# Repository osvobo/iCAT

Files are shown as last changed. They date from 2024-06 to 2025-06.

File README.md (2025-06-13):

# iCAT: A Multifunctional Open-Source Platform for Advanced Light Microscopy
<br>

"i" - Intuitive: iCAT represents an innovative approach to light microscopy, incorporating advanced features like intuitive axial rotation and tracking. It introduces a novel solution for imaging and studying biological specimens with enhanced capabilities, pushing the boundaries of traditional microscopy techniques. <br>
"C" - Controlled: iCAT offers precise control over specimen rotation, temperature regulation, and lighting conditions, ensuring optimal imaging conditions and experimental reproducibility. <br>
"A" - Axial: iCAT's unique capability to rotate specimens along their axial axis sets it apart from conventional light microscopy techniques, allowing researchers to observe dynamic processes and capture detailed time-lapse sequences. <br>
"T" - Tilt: iCAT offers the unique capability of "Controlled Axial Tilt" providing researchers with a 360-degree perspective. This groundbreaking feature empowers researchers to examine specimens in three dimensions, facilitating the exploration of dynamic cellular processes, developmental biology, and beyond. 
<br><br>

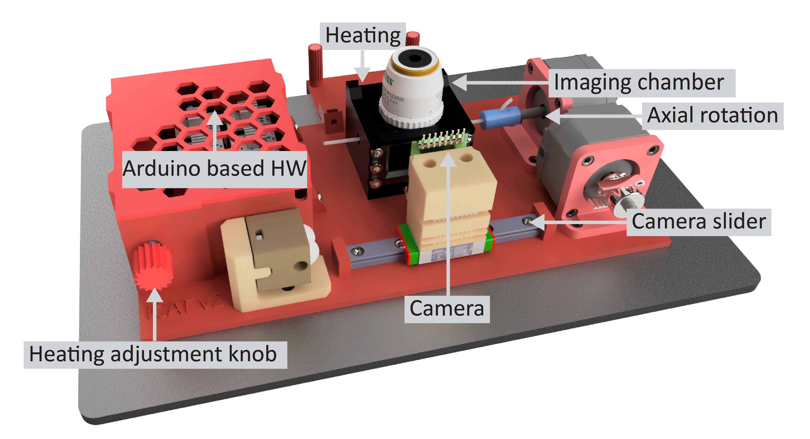
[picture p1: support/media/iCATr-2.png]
<div style="page-break-before: always;">

# Introduction
In the field of light microscopy, imaging specimens from multiple angles and maintaining controlled temperature conditions are crucial for comprehensive and accurate analysis. To address these challenges, we present iCAT, an open-source multifunctional accessory designed to revolutionize light microscopy capabilities. iCAT enables the rotation of specimens along their axial axis, incorporates an in-built thermometer and Peltier element for precise temperature control, features an integrated LED light source, and is equipped with a camera. This versatile device, controlled by an Arduino-based electronic circuit and a Processing based graphical user interface (GUI), allows researchers to capture detailed images and videos of both fixed and live specimens, such as C. Elegans, Zebrafish, Drosophila, mouse embryos etc. The iCAT accessory, which can be easily 3D-printed and assembled using readily available electrical components, serves as a powerful tool for investigating dynamic cellular processes and complex developmental phenomena. The iCAT 3D model can be visualized in this [video](https://youtu.be/drMLpkQK6RA). 
<br><br>
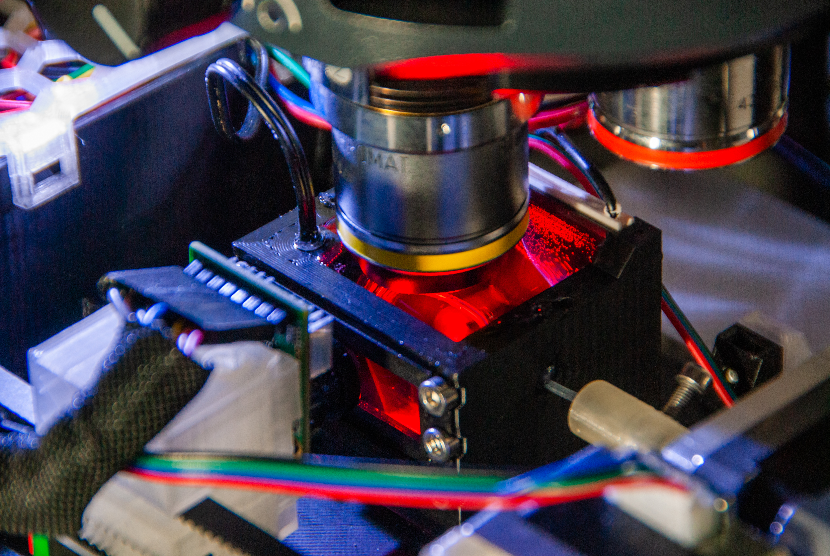
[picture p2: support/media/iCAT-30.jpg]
<div style="page-break-before: always;">

# Design and Functionality
## Rotational Capabilities
The ability to capture images and videos of a specimen from multiple angles is essential for comprehensive analysis. iCAT incorporates a motorized rotation mechanism that enables controlled and precise specimen rotation along its axial axis. Researchers can program the desired rotation parameters through the device's graphical user interface (GUI) and monitor the rotation progress in real-time. The iCAT accessory provides unprecedented flexibility in imaging and studying dynamic processes that require specimen repositioning during time-lapse experiments, such as cell migration or morphogenesis. 
<br>
## Temperature Control
Maintaining a stable and controlled temperature environment is crucial for studying living specimens. iCAT addresses this requirement through an in-built thermometer and a Peltier element. The thermometer constantly monitors the specimen's temperature, while the Peltier element actively regulates the temperature within a specified range. This temperature control feature ensures optimal imaging conditions and facilitates accurate analysis of temperature-sensitive biological processes, including embryonic development. <br>
## Illumination and Camera System
An appropriate and adjustable uniform light source is critical for obtaining images using the internal camera. The intensity of the LED can be adjusted via the GUI and minimizes the need for further external light sources during specimen rotation using the built-in camera. The GUI can control the image resolution, providing researchers with flexibility in controlling camera speed. 
<br><div style="page-break-before: always;">

# Fabrication and Accessibility
One of the key advantages of iCAT is its open-source nature, which promotes accessibility, customization, and collaborative development. The device can be fabricated using 3D printing technology, ensuring low-cost production and ease of assembly. Additionally, all the electrical components required for iCAT can be readily obtained for less than $300, making it feasible for researchers with varying resources and expertise levels to replicate and utilize the device in their laboratories. The control circuit, based on the Arduino platform, is well-documented and can be modified to accommodate specific experimental requirements. 
<br><br>
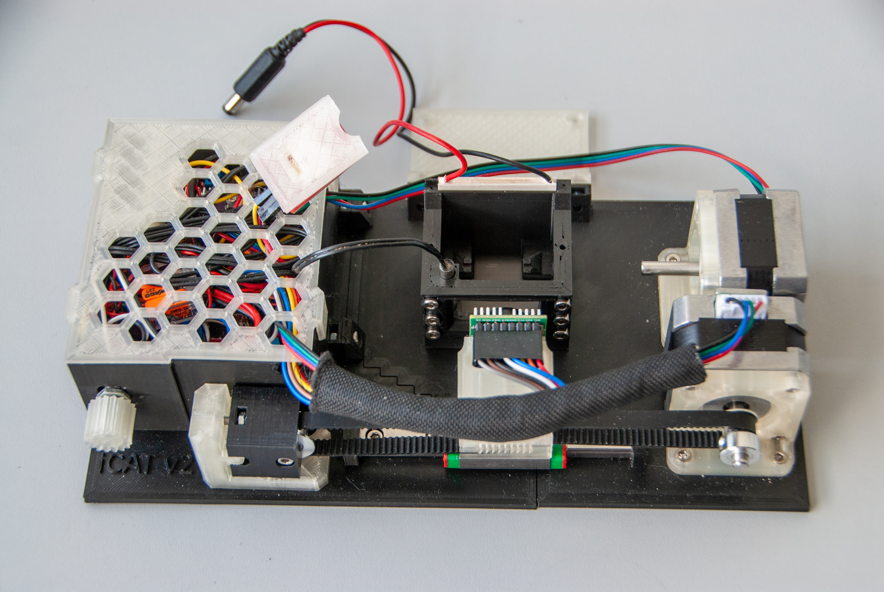
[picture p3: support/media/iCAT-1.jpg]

<br>

# Applications and Impact
The multifunctional capabilities of iCAT open up new avenues for biological research, particularly in the fields of developmental biology, neurobiology, and cellular imaging. By enabling precise specimen rotation, temperature control, illumination, and imaging, iCAT empowers researchers to investigate dynamic processes, observe intricate morphological changes, and capture real-time developmental events. The device has proven particularly effective in the study of model organisms such as C. elegans, Zebrafish, where cell migration, organogenesis, and tissue development necessitate the ability to reposition specimens during time-lapse experiments. <br>
Furthermore, the open-source nature of iCAT fosters collaboration and encourages the scientific community to contribute to its development and enhancement. By sharing the design, software, and documentation, we aim to accelerate scientific progress and provide a versatile tool that can be adapted and customized for specific research needs. <br><br>

# Conclusion
iCAT represents a significant advancement in light microscopy, addressing the limitations of traditional techniques by offering a multifunctional accessory that combines rotation, temperature control, illumination, and imaging capabilities. The open-source nature of iCAT ensures its accessibility, affordability, and adaptability, making it an invaluable tool for researchers in the biological sciences. By providing a platform to investigate dynamic processes and complex developmental phenomena, iCAT contributes to our understanding of fundamental biological mechanisms and facilitates discoveries in various fields of study.
<br><div style="page-break-before: always;">

# Methods
## Supplies
One of the key advantages of iCAT is its open-source nature, which promotes accessibility, customization, and collaborative development. The device can be fabricated using 3D printing technology, ensuring low-cost production and easy assembly. All the electrical and mechanical components required for iCAT can be readily obtained for less than $300, making it feasible for researchers with varying resources and expertise levels to replicate and utilize the device in their laboratories. For an overview of the required components, see the illustrative image and list below.
<br><br>
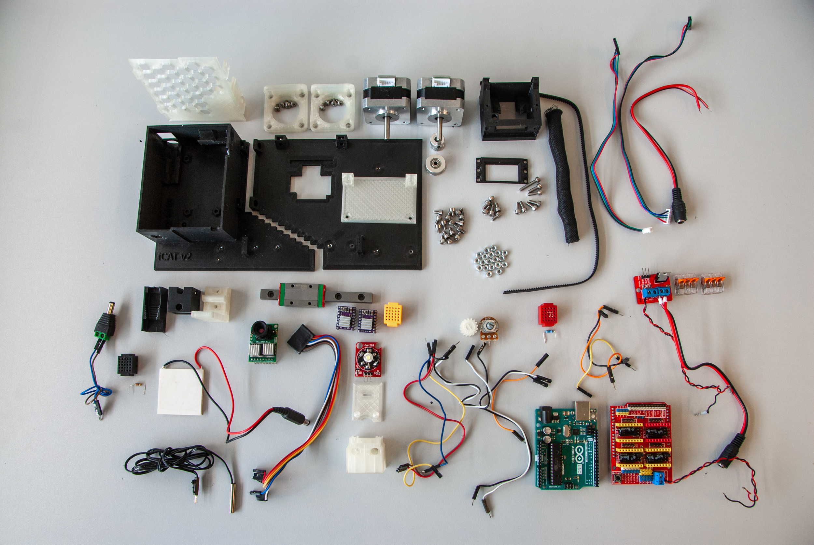
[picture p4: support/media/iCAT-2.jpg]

<br>

### Electronics:
Arduino Uno Rev3, 1x <br>
Arducam 5MP Plus OV5642, 1x <br>
IRF520 Driver Module, 1x <br>
CNC Shield V3, 1x <br>
DRV8825 Stepper Motor Driver, 2x <br>
17HS2408 Stepper Motor, 2x <br>
Peltier plate module TEC1-12706, 1x <br>
NTC Thermistor 10K 1% 3950, 1x <br>
4.7 kOhm resistor, 1x <br>
10 kOhm resistor, 1x <br>
10 kOhm potentiometer, 1x <br>
3W High Power LED Module LED with PCB Chassis for Arduino, 1x <br>
12V 3A Power Supply, 1x <br>

### Accessories:
GT2 Pulley 16 Teeth 5mm bore 6 mm width, 1x <br>
GT2 Idler 20 Teeth 5mm bore 3 mm width without teeth, 1x <br>
GT2 Open Timing Belt 2mm Pitch 6mm Width, 1x <br>
MGN9H 100mm linear guide rail with carriage, 1x <br>
Stainless Steel DIN912 Hexagon Hex Socket Head Cap Allen Bolt Screw, M3x4 (22x), M3x5 (4x), M3x6 (8x), M3x14 (1x) <br>
M3 hex nut, 20x <br>
Microscope Cover Glass, 24x40mm, 10x <br>
Lubricant in the syringe, 1x <br>
Sleeving Cord Protector, 6-12 mm, 1x <br>
Neodymium Magnet 5mm x 2mm, 8x <br>
FEP tube clear 0.8 I.D./1.2 O.D., 10-25 m <br>
FEP tube clear - other sizes, 5 m <br>
Silicon rubber tube 1x2 mm, 3 m <br>

### Wiring:
Female Plug 12V DC Power Pigtail Cable Jack, 2x <br>
Female and Male DC Connectors 2.1x5.5mm, 1x <br>
Crimp Terminals Set Kit, 1x <br>
Dupont Line M-M + F-M + F-F Jumper Wire 10cm, 20CM, 30x <br>
WAGO Terminals Series Splicing Connector 221-413, 2x <br>
Mini Solderless Prototype Breadboard, 3x <br>
Black Jumper Caps, 2x <br>

### 3D print:
3D printer, 1x <br>
3D Printer Filament 1.75mm - transparent, black, 2x <br>

### Tools:
Pipette Pump 10ml, 1x <br>
Borosilicate Glass Pasteur Pipettes, 1x <br>
Crimping Tools SN-58B + 4 jaws, 1x <br>
Screwdriver Set, 1x <br>

*NOTE: The complete shopping list is in the [components sheet](support/support.xlsx).* <div style="page-break-before: always;">

## Instructions
### Part 1: 3D printing
All 3D-printed parts can be made using PETG or PLA filaments. For the 'chamber', it is recommended to use a transparent material for the first three layers to allow the use of transmitted light from a microscope. The 'chamber' can be printed in approximately 4 hours, requiring 10.5 meters of filament. For the remaining parts, black filament is recommended to minimize light reflections. Printing these parts takes about 25 hours and consumes 75 meters of filament. The individual STL and 3MF files and the complete Fusion360 project are in the [3D folder](support/3D). The complete iCAT model can also be loaded from the [mesh folder](support/mesh). The STL data can be visualized using 3D slicer software, while the OBJ file can be opened with any mesh viewer, such as the 3D Viewer application in Windows. <br>

### Part 2: iCAT assembly
To assemble iCAT from individual parts, follow the instructions below. If needed, see the [pinout sheet](support/support.xlsx), and the wiring diagram. 
<br><br>
<!-- ![pic](support/fritzing/iCAT_v2.png) -->
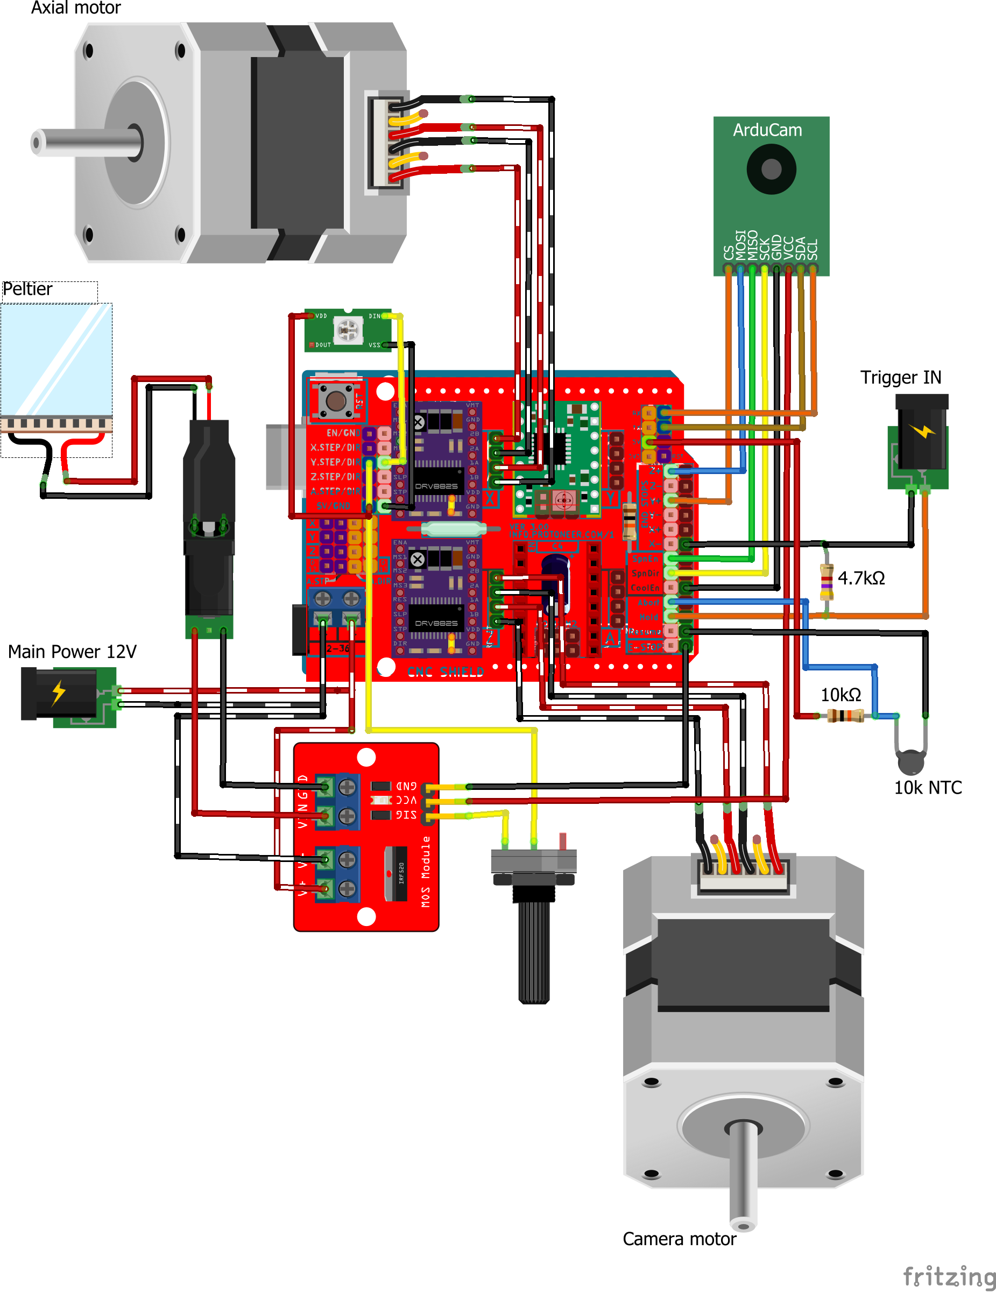
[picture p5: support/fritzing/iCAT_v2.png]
<span></span>

1. Insert all M3 nuts and four neodymium magnets into both 'base' parts. 
<br><br>
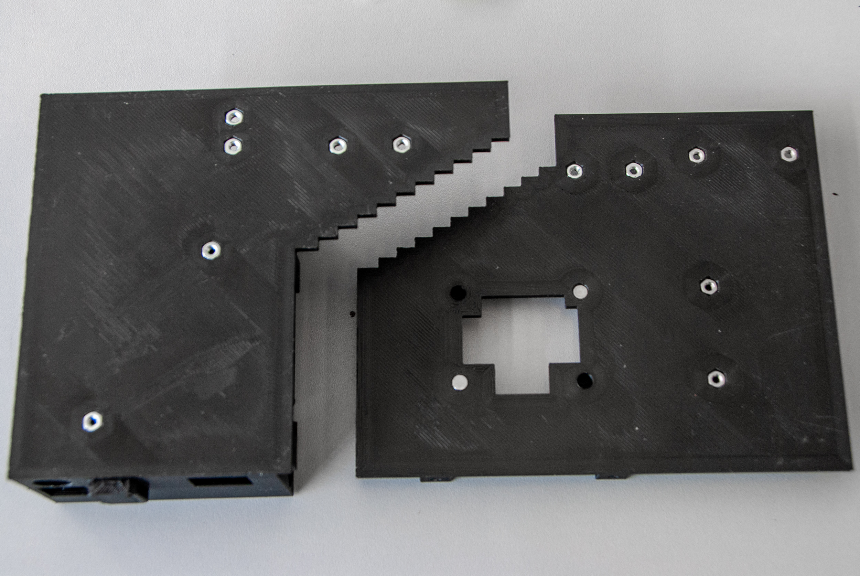
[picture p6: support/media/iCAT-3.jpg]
<span></span>

2. Slide the linear guide into the 'base-1', put both 'base' parts together, and secure the connection between them with two M3x6 screws. Attach the 'mounting plate' using two M3x6 screws and secure the 'linear guide' with four M3x5 screws.
<br><br>
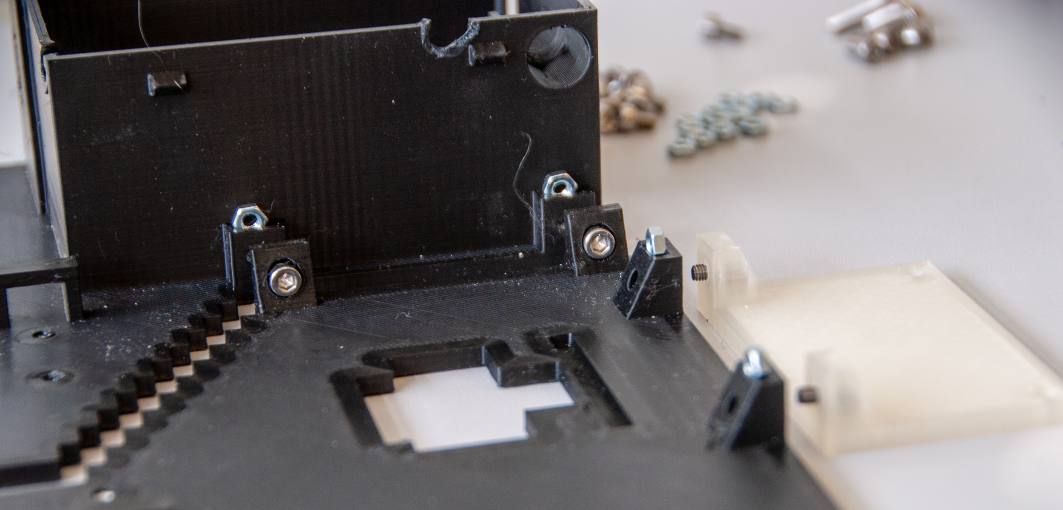
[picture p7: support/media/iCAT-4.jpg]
<span></span><div style="page-break-before: always;">
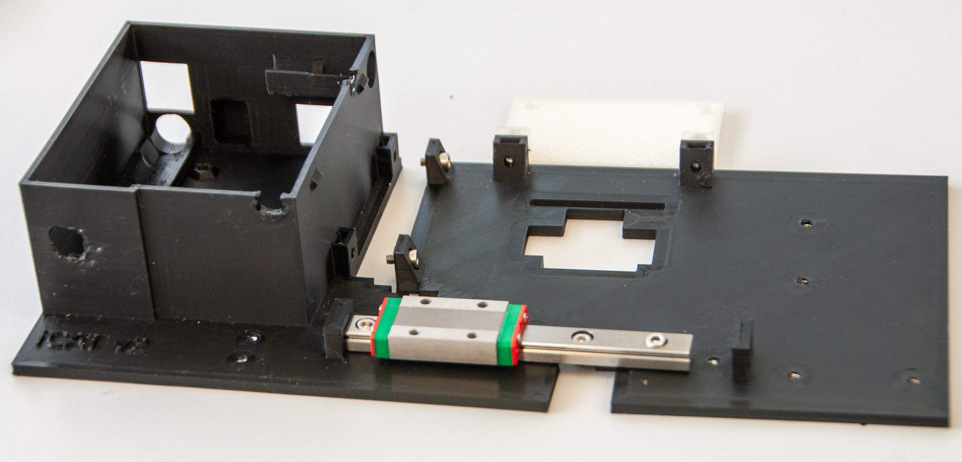
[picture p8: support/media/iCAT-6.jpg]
<span></span>

3. Fix the 'motor plates' to 'NEMA motors' using eighth M3x4 screws according to the image below. Attach 'GT2 Pulley' to one of the 'NEMA motor'. The pin connections of this 'NEMA motor' need to be oriented vertically. 
<br><br>
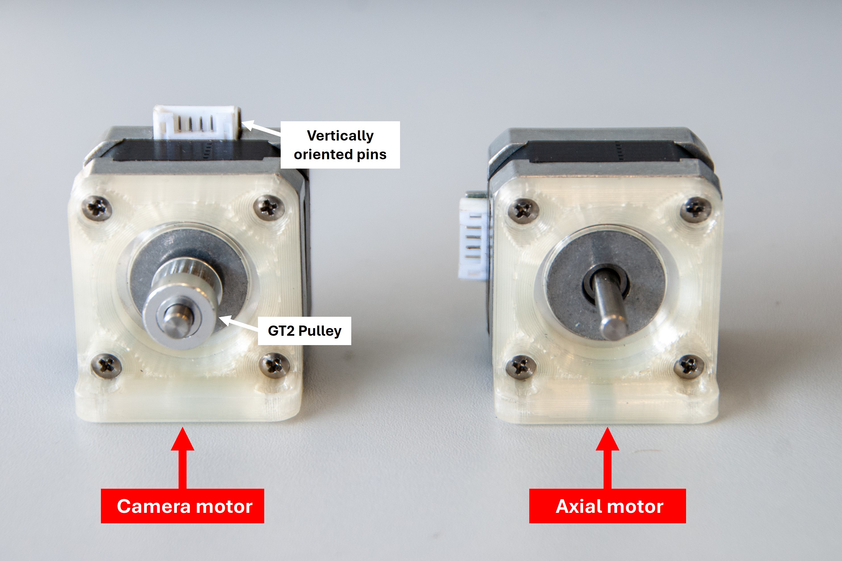
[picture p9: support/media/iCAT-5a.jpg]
<span></span>
<div style="page-break-before: always;">

4. Secure the 'motor plates' on the 'base' using M3x4 screws. 
<br><br>
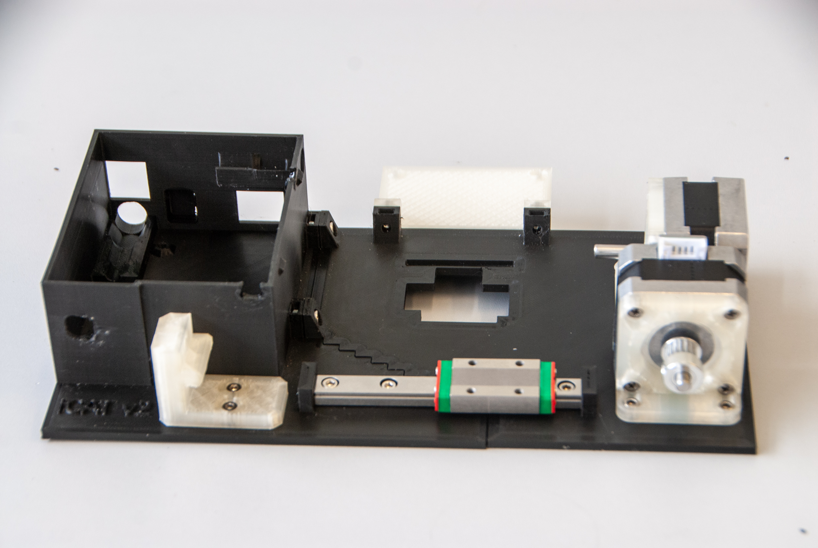
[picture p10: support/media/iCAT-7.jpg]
<span></span>

5. Insert three M3 nuts into the 'cargo plate-2' and attach the 'GT2 Idler' to it using a M3x14 screw. Cut 33.5 cm of 'GT2 Timing Belt' and pass it through the 'idler'. Fasten the ends of the belt inside the 'cargo' according to the image below. 
<br><br>
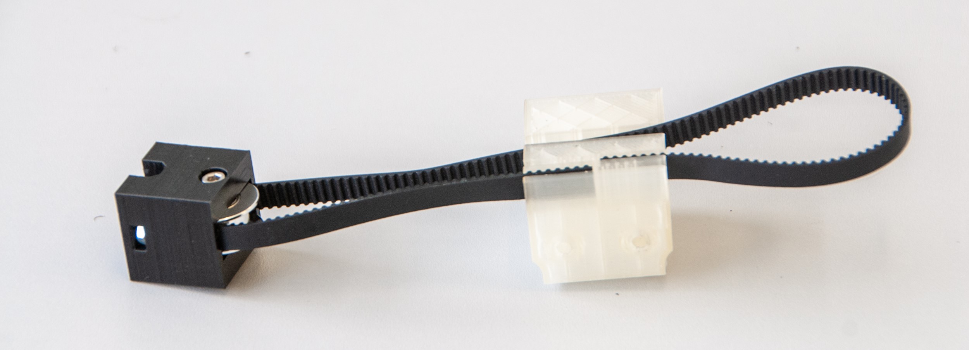
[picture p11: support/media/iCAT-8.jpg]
<span></span>
<div style="page-break-before: always;">

6. Secure the 'cargo' to the 'Linear Guide Carriage' using two M3x4 screws and place the belt on the 'GT2 Pulley' that was previously attached to one of the 'NEMA motors'. Attach the 'cargo plate-2' to the 'cargo plate-1' using prepared screws. Do not overtighten these screws, otherwise the 'base' will bend. 
<br><br>
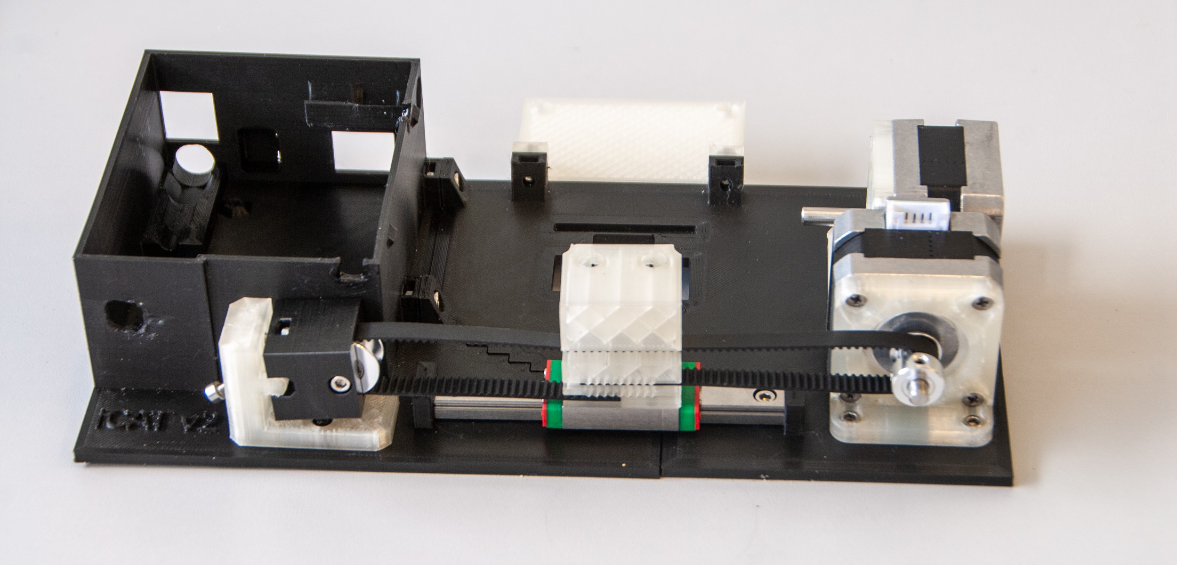
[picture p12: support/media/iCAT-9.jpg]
<span></span>

7. Insert the M3x6 screws into the mounting holes of the 'Arduino Uno' and plug the 'CNC shield' onto the 'Arduino', ensuring that the pins are properly aligned with the corresponding headers. To adjust micro-stepping (1/16 step), set up the 'M2 pin' of the 'CNC Shield' HIGH by connecting the 'black jumper caps', as shown in the image below. Attach the 'DRV8825 Stepper Motor Drivers' to the 'CNC Shield' and connect the power supply wires to both the shield and the 'WAGO terminals'. 
<br><br>
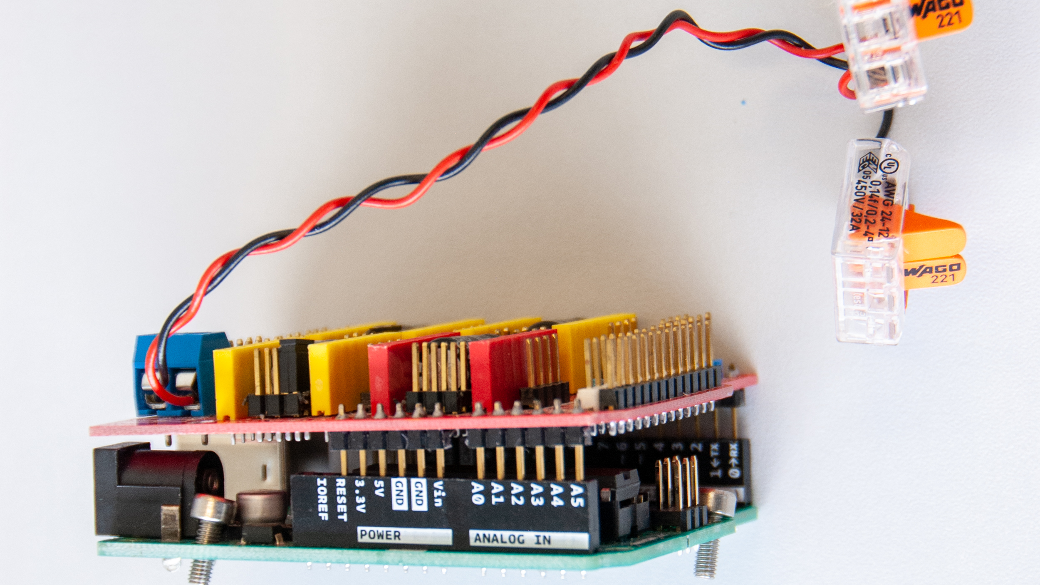
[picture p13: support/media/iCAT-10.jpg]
<span></span>

<i>NOTE: Before proceeding any further, the voltage reference (V<sub>REF</sub>) that corresponds to the maximum current that will flow to the stepper motors needs to be set. The maximum current of used stepper motors is 1.8 A. To calculate the Vref, use this equation: <br>
**V<sub>REF</sub> = I<sub>max</sub>/2** <br>
**V<sub>REF</sub> = 1.8/2 = 0.9 V** <br>
In order to set up the Vref, plug in the 'Arduino UNO' with 'CNC Shield' and the 'DRV8825 Stepper Motor Drivers' to the USB port, connect the negative probe of the multimeter to the GND, connect the positive probe of the multimeter to the screwdriver tip, set the multimeter to DC Voltage measurement, and use the screwdriver to turn the potentiometer until you get the calculated voltage.</i>
<br>

8. Similarly to the previous step, interconnect the 'WAGO terminals' with the 'IRF520 Driver Module' using additional power wires. Next, connect the wire end of the first 'Pigtail Cable Jack' to the 'WAGO terminals'. The wire end of the other 'Pigtail Cable Jack' needs to be connected to the 'IRF520 Driver Module'. If needed, crimp the ends of any wires. 
<br><br>
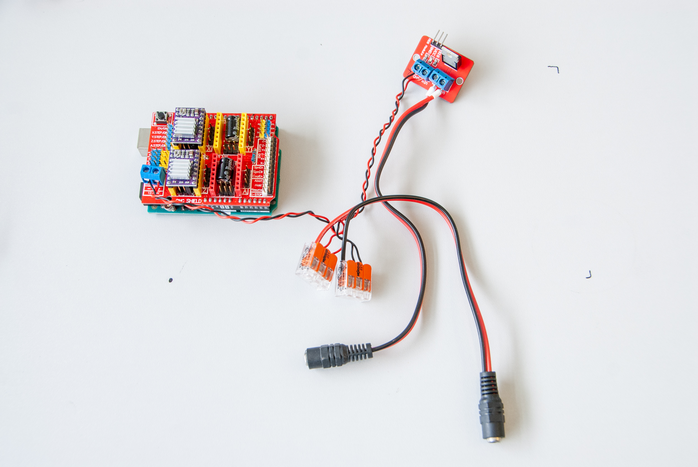
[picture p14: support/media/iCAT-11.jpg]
<span></span>

9. Attach the 'Ardunio UNO' coupled with the 'CNC Shield' and all the wirings to the 'base' using previously inserted screws. 
<br><br>
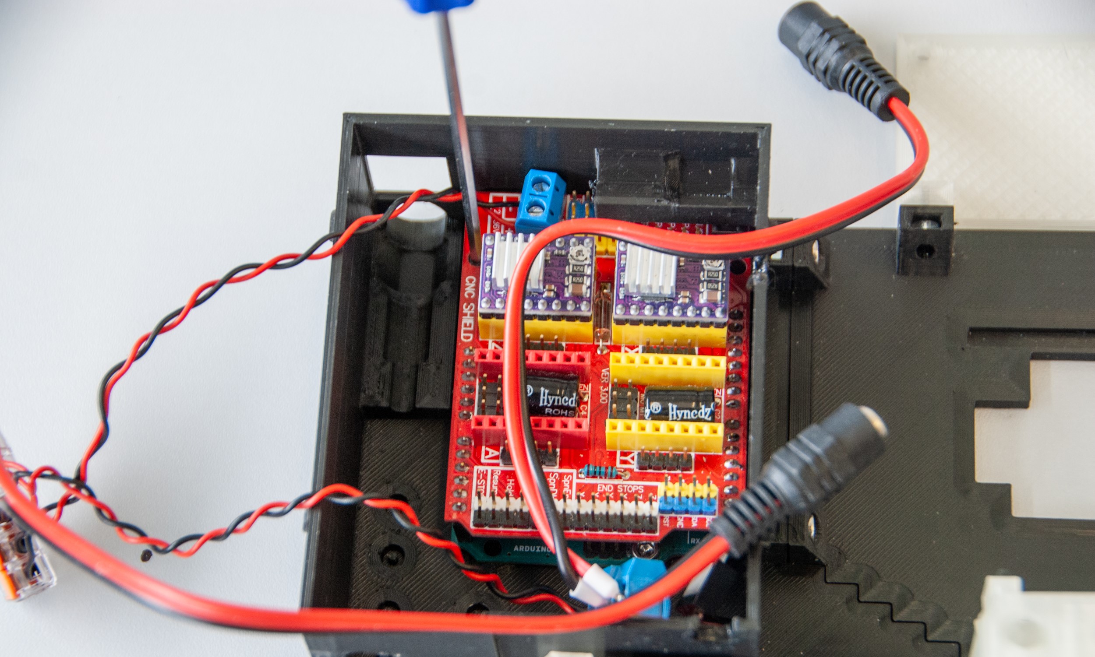
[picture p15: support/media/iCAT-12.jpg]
<span></span><div style="page-break-before: always;">

10. Install wiring components on three mini breadboards according to the image below. First, plug '10 kOhm resistor' into the 'Thermistor breadboard'. Shorten the resistor leads, if necessary. Plug '10 kOhm thermistor', while one of its leads connects it with the resistor. Connect the 'Male-Female Dupont wire' to it. This will be connected to the analog input ('Abort pin') on the 'CNC shield' later on. The other 'Dupont wires' need to be connected to the other thermistor lead (ground) and to the second resistor lead (5 V). Second, prepare the 'Trigger IN' breadboard by plugging a '4.7 kOhm resistor' into it and connecting its terminals to the 'Male DC connector'. 'Dupont wires' will be connected to both of these resistor leads later on (step 14) to the ground and to the analog input ('Hold' pin) on the 'CNC Shield'. Third, plug '10 kOhm potentiometer' into the last breadboard. Two 'Dupont wires' will be connected to the side and the middle terminals later on, connecting it to 'PWM digital input' ('Step Y' pin of the 'CNC shield') and to the 'IRF520 Driver Module' signal input. If needed, crimp the ends of any wires. 
<br><br>
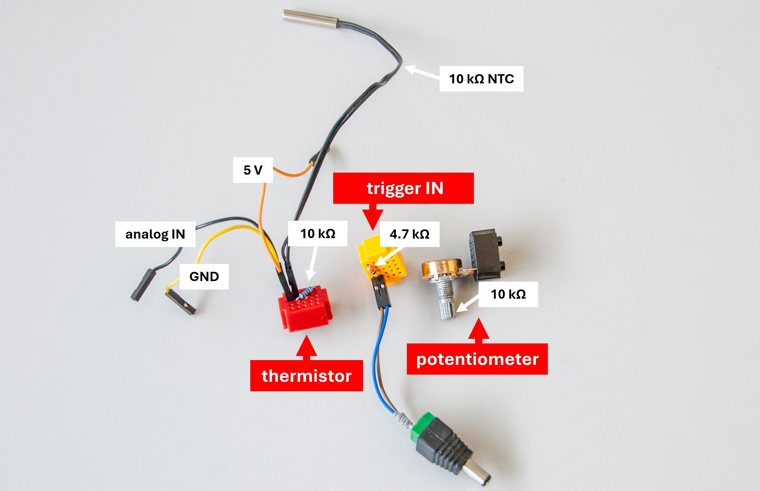
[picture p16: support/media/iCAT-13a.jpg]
<span></span><div style="page-break-before: always;">

11. Install the 'Potentiometer breadboard' and 'DC Female pigtail' in to the 'base' and cover it with the 'base adapter'. 
<br><br>
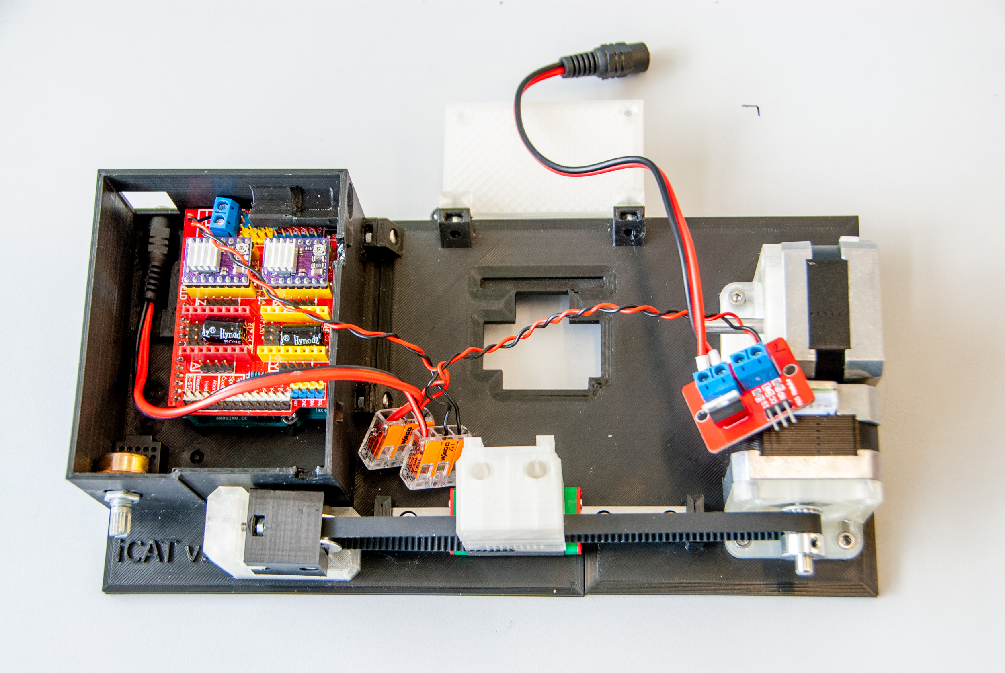
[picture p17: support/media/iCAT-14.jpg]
<span></span>

12. Install the 'Trigger IN breadboard' and fit 'Male DC connector' in the 'base adapter'. 
<br><br>
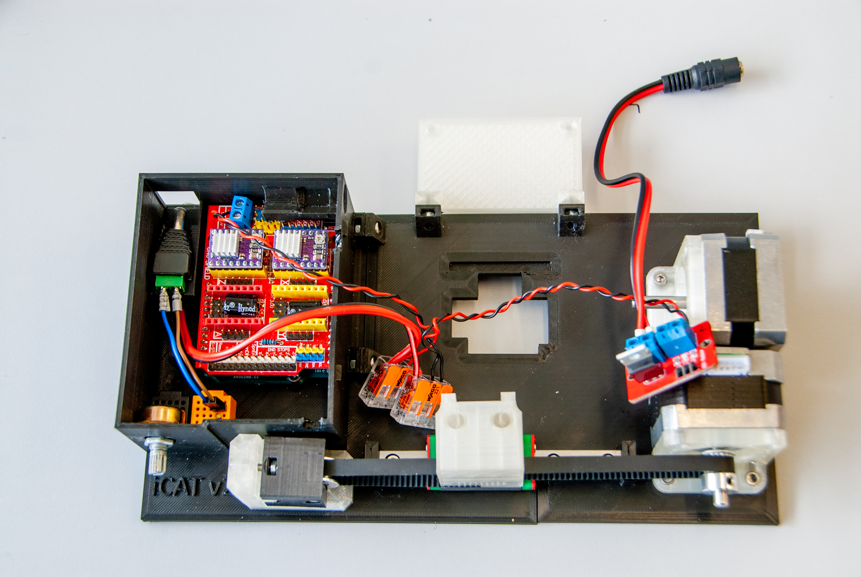
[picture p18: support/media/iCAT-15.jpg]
<span></span><div style="page-break-before: always;">

13. Install the 'IRF520 Driver Module' and plug its 'Dupont wires' (ground, 5 V). Plug the signal input as described in step 10. Fit 'Male DC connector' connected to 'IRF520 Module' in the upper right corner of the 'base'. Secure the 'potentiometer' by its nut and attach the 'knob' to it. 
<br><br>
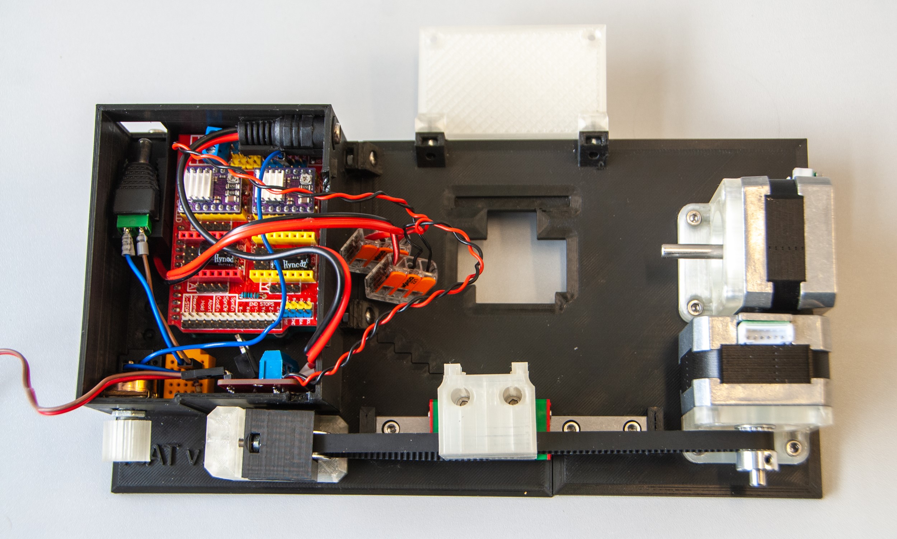
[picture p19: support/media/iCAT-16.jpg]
<span></span>

14. Install the 'Thermistor' breadboard in the 'base'. Connect 'Dupont wires' of all the 'breadboards' as described in step 10. Connect 'LED' to 5 V, ground, and digital output ('Dir Y' pin) on the 'CNC Shield'. Plug eight 'Dupont wires' to the 'Arducam' and connect them to the 'CNC Shield' according to the [pinout sheet](support/support.xlsx) and the wiring diagram. Test the functionality of the device at this point before attaching the 'lid'. 
<br><br>
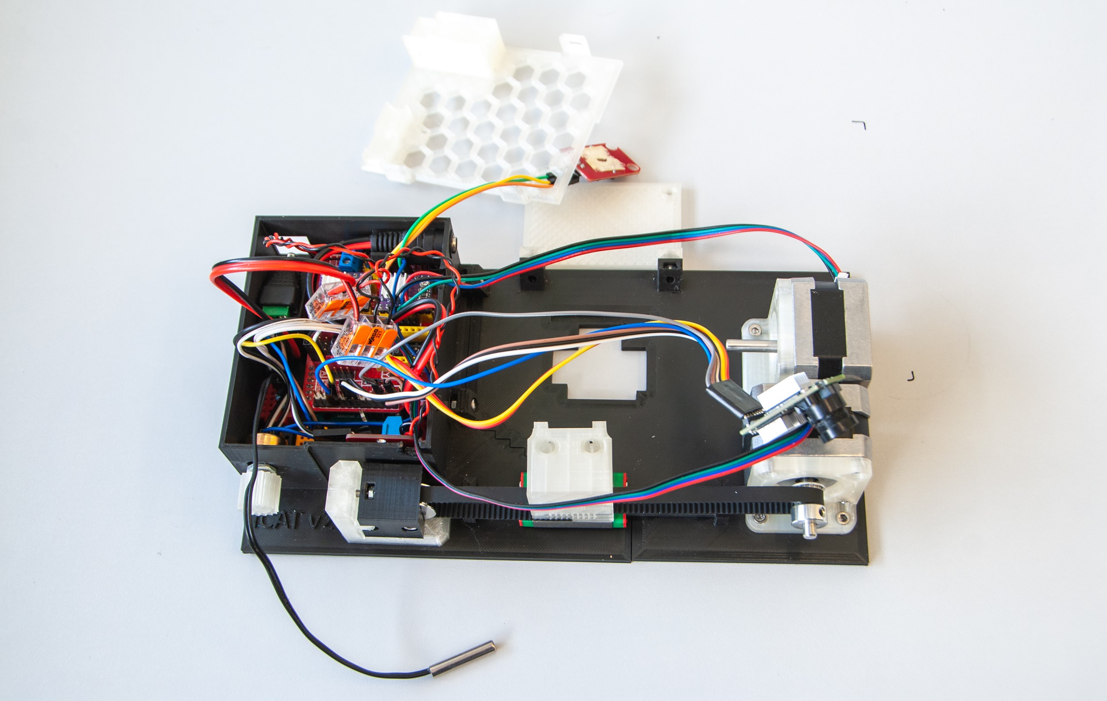
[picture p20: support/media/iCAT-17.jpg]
<span></span><div style="page-break-before: always;">
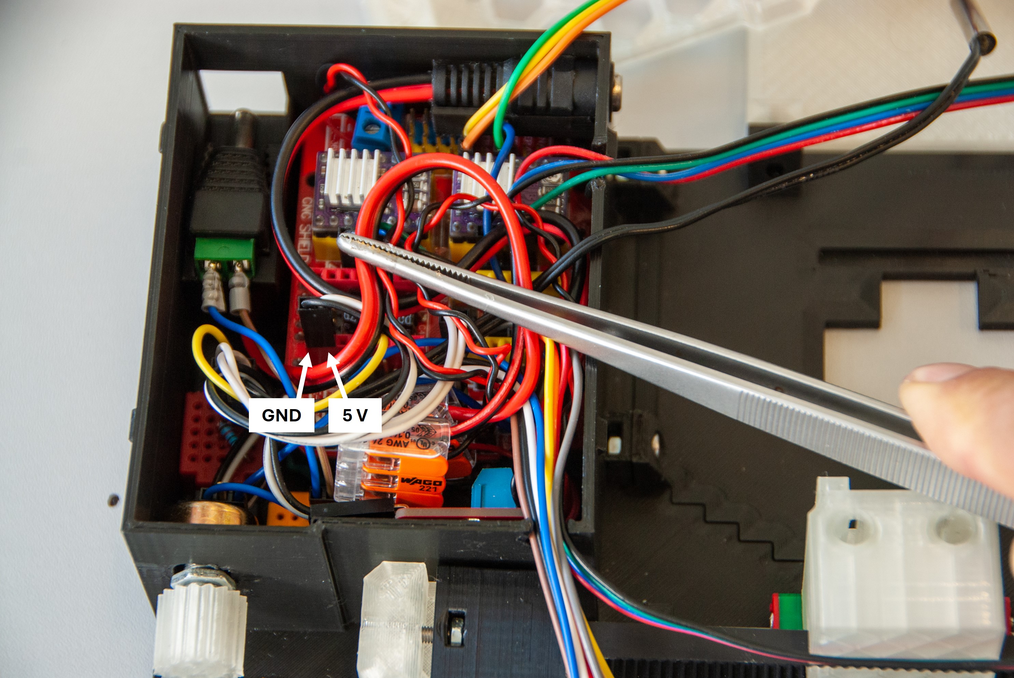
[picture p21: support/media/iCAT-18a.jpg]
<span></span>

<i>NOTE: It is possible to use 5 V and GND pins of unoccupied driver bays on the 'CNC Shield' to connect the 'IRF520 Driver Module' and the 'thermistor'.</i>

15. Attach the 'lid' to the 'base' and attach 'Arducam' to the 'cargo' using two M3x4 screws. Install a Sleeving Cord Protector to cover the wiring of the camera. 
<br><br>
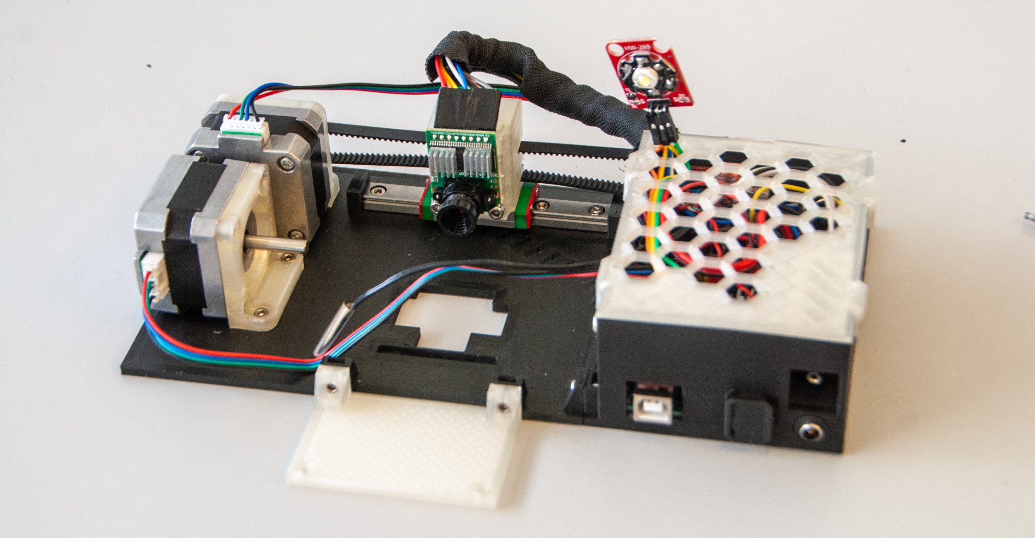
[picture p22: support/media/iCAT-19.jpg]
<span></span>

16. Use 'mounting screws' to connect the iCAT's 'mounting plate' to the stage of the microscope. 
<br><div style="page-break-before: always;">

iCAT has so far been successfully mounted and used with several upright microscopes. The current imaging chamber design is optimized for upright systems and is compatible with a 0.8 mm inner diameter / 1.2 mm outer diameter FEP tube. To accommodate this configuration, the microscope's focus travel range must be at least 12 mm to reach the sample, and the objective working distance should exceed approximately 0.6 mm (half the FEP tube's outer diameter). <br>
To use the FEP tube with a larger inner diameter, the imaging chamber must be modified by enlarging the FEP hole in the [Fusion360 design file](support/3D/iCAT_v2%20v91.f3d). This modification can be performed by the user or requested by submitting a new [issue](https://github.com/osvobo/iCAT/issues/new) on the GitHub repository.
<br><br>
**ZEISS Axio Examiner:**<br>
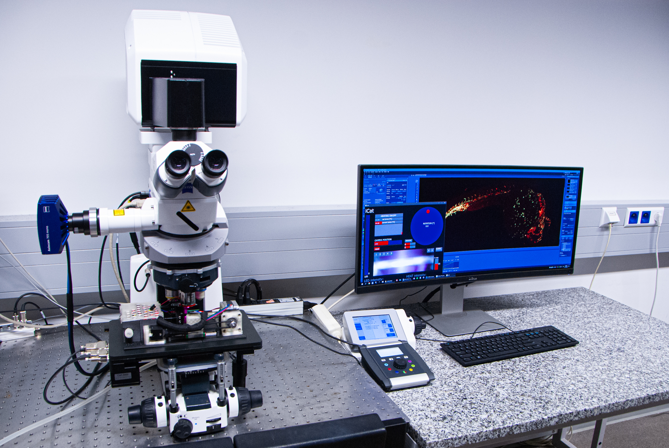
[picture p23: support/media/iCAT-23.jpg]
<span></span>
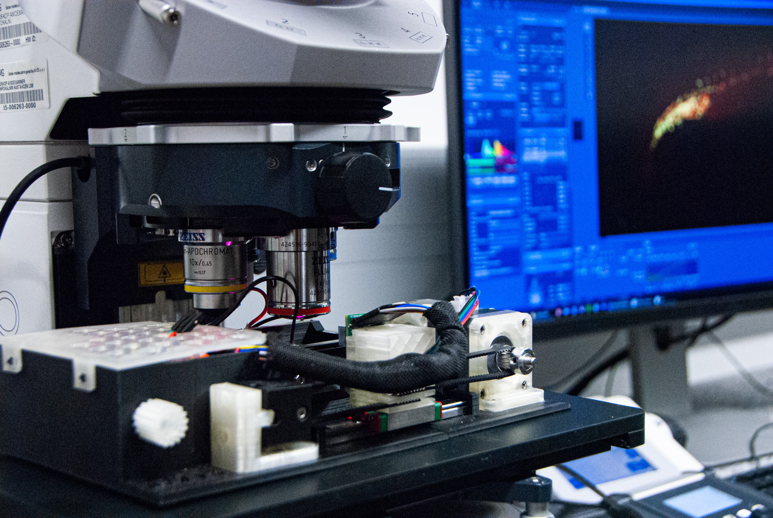
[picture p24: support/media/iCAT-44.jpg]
<span></span>
<div style="page-break-before: always;">

**ZEISS Axio Zoom.V16:**<br>
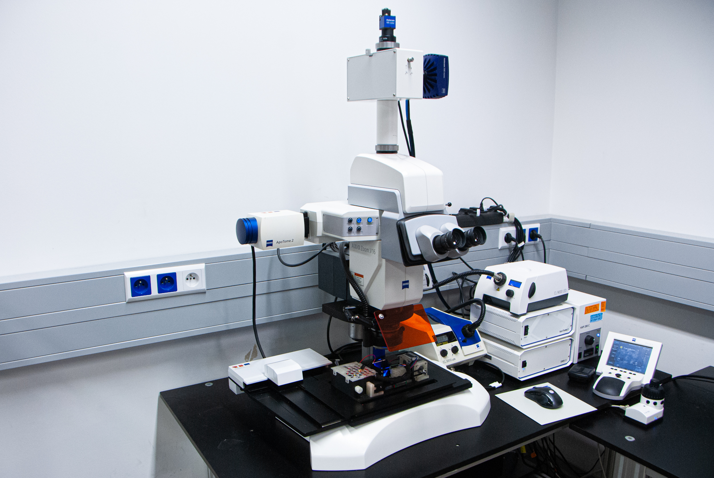
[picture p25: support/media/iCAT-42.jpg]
<span></span>
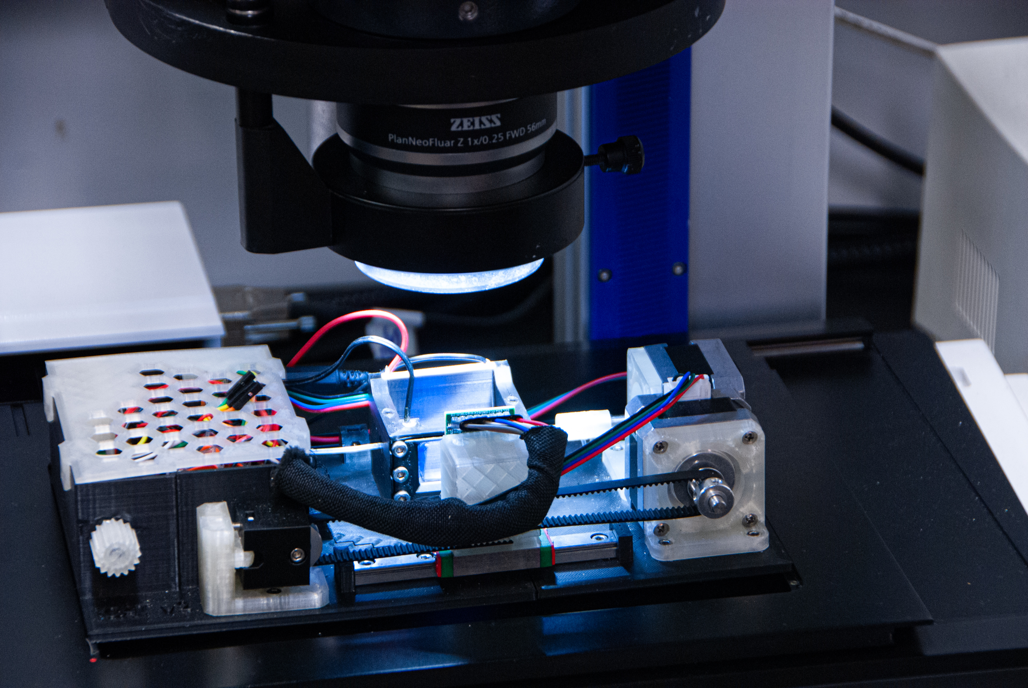
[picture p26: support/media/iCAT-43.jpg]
<span></span>
<div style="page-break-before: always;">

### Part 3: Chamber assembly
To install the 'cover' on the sample 'chamber', follow these steps: 
<br>
1. Apply grease around the perimeter of the 'chamber' window and gently place the 'Microscope Cover Glass' (coverslip) onto the applied grease. Ensure that the grease spreads evenly under the coverslip and that it is centered.
<br><br>
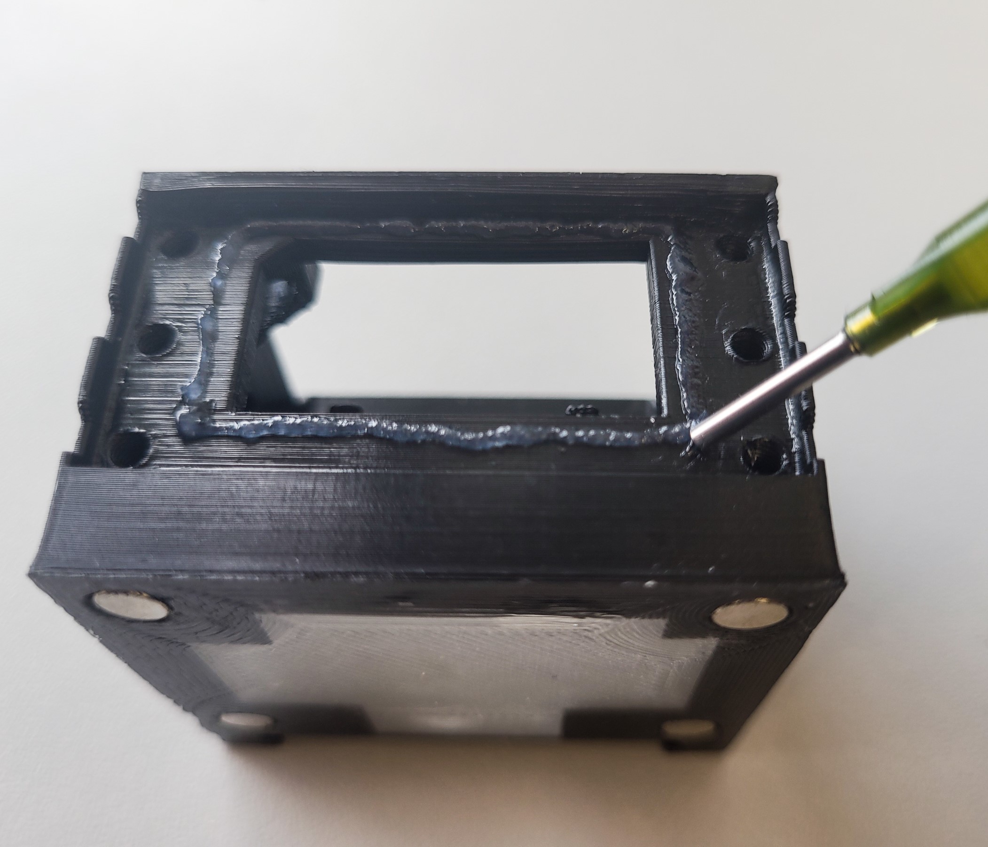
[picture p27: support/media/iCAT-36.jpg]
<span></span>
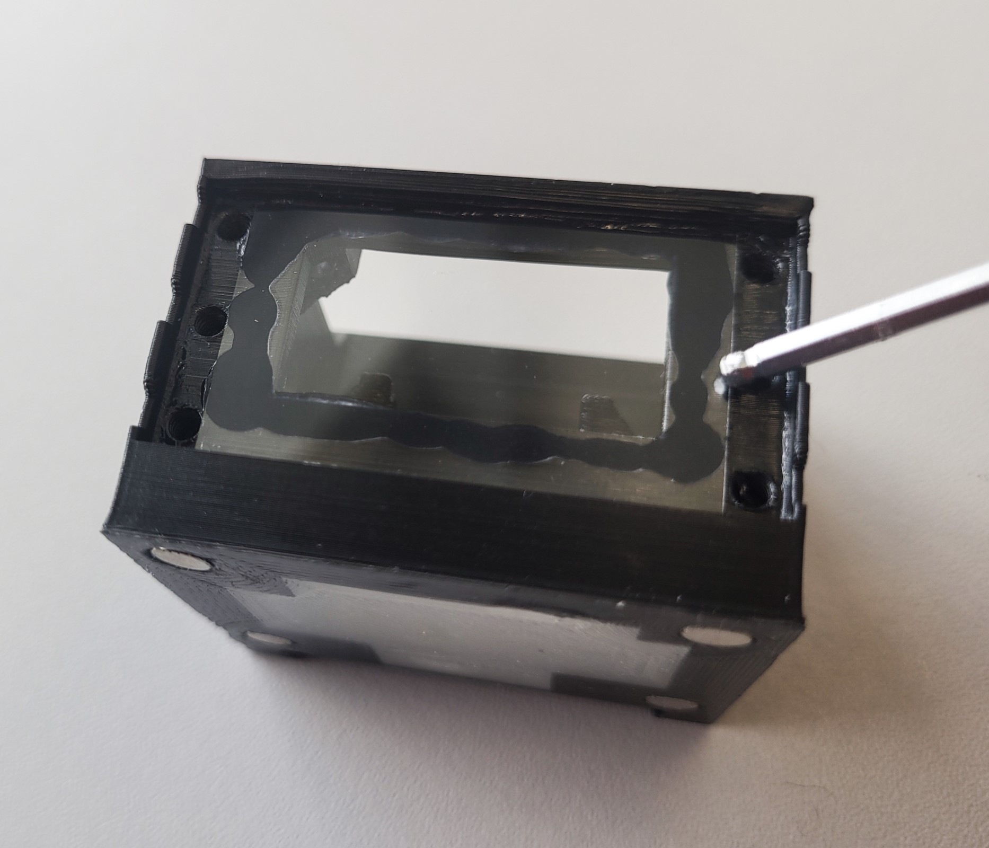
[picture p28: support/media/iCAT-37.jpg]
<span></span>

2. Secure the attached coverslip with eight M3x4 screws, and tighten the screws gently.
<br><br>
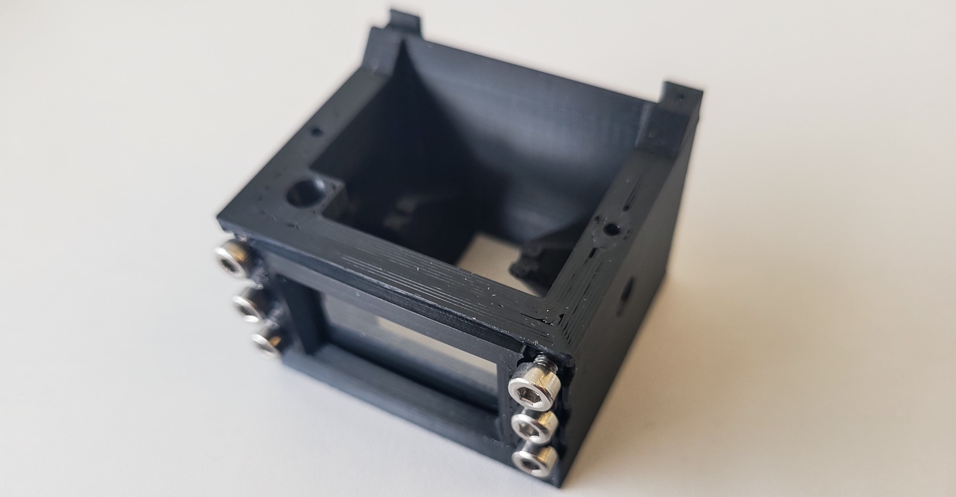
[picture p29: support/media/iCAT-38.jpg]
<span></span>

<i>NOTE: Be careful when tightening the screws, as the coverslip is fragile. It is recommended to tighten the screws gradually in several rounds, testing the 'chamber' after each round by filling it with water. If no leaks are observed, let the 'chamber' sit overnight on a soft tissue surface. No leaks should be present the following day.</i>
<br><div style="page-break-before: always;">

3. Slide the Peltier element to the back of the 'chamber'. Place the 'chamber' on the 'base', and connect it to the female DC connector on the side. Focus the camera using the adjustment ring. All iCAT connectors are depicted below. 
<br><br>

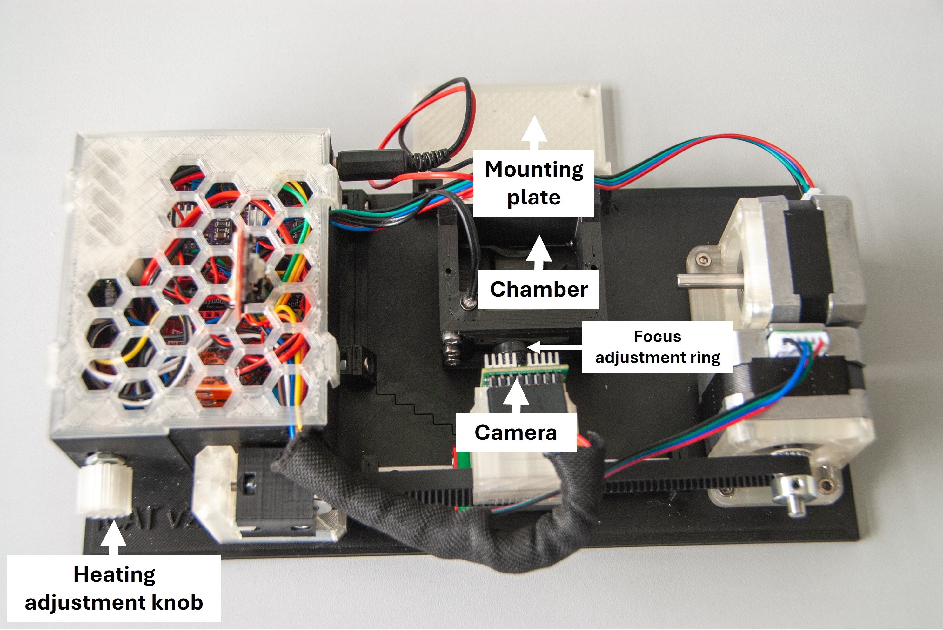
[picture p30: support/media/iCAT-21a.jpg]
<span></span>

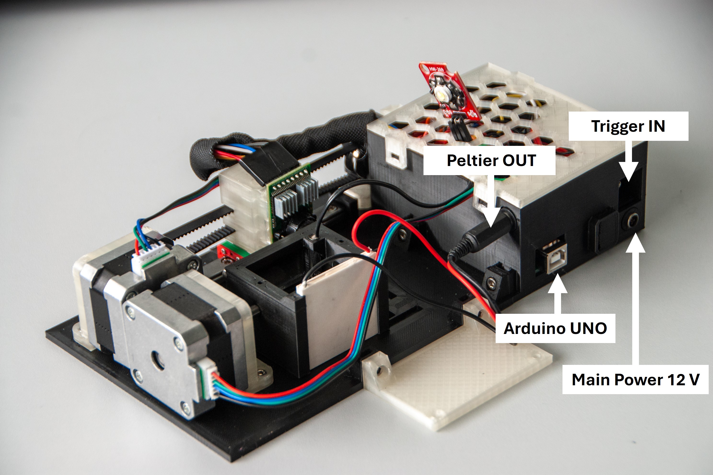
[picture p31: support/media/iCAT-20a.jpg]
<span></span>
<div style="page-break-before: always;">

### Part 4: Installation
1. Download the entire repository, or simply download the [Arduino sketch folder](main/), the [```main.pde```](main.pde) Processing sketch, and install the [Processing application](https://processing.org/download). <br>

*NOTE: If you run the [```iCAT.exe```](processing/iCAT.exe) file directly, you will need to install OpenJDK17, as the [Processing sketch folder](processing/) does not contain Java.*<br>

2. Install the [Arduino IDE](https://www.arduino.cc/en/software). <br>
3. Open the Arduino IDE by opening the [```main.ino```](main/main.ino) file. Next, go to the Library Manager and install the [AccelStepper](https://www.airspayce.com/mikem/arduino/AccelStepper/) and [ArduCAM](https://github.com/dennis-ard/ArduCAM) libraries. Once both libraries are installed, press the 'Verify' button to ensure the installation is successful. <br>
4. Check the path of ```memorysaver.h``` file by hovering the mouse over its name at row 5 in the line ```#include "memorysaver.h"```. Then navigate to its folder and replace it with the [```memorysaver.h```](main/memorysaver.h) file provided, which has the camera definition uncommented: <br>
```#define OV5642_MINI_5MP_PLUS``` <br>
5. Test the iCAT by connecting the Arduino to the PC using USB-B cable, connecting the '12 V main power', the 'trigger IN', and the 'Peltier connector'. Open the [```main.pde```](main.pde) and click on the **Run button** in the upper left corner, this will open the Graphical User Interface (GUI) of the iCAT. 
<br><br>

![pic](support/media/processing.jpg) 
<br>

6. Select the port using **Port selection button** to which the iCAT is connected. After successful connection, the message will appear in the console: *"iCAT is ready!"*. <br>
7. Test the functionality of the main components: the LED, heating, motors, and camera. Adjust the camera focus using the [Focus adjustment ring](#iCAT-21a).
<br>

### Part 5: General usage
These instructions can be used to mount and image zebrafish embryos between 0 – 10 dpf using iCAT and confocal microscope or macroscope. Other specimens can be imaged as well. If needed, simply use larger FEP tubes to image larger samples. In such a case, however, the 'chamber' needs to be modified. Using the iCAT in combination with other upright microscopes should be possible; however, this has not been tested. Following [video](https://youtu.be/bGU-32gU9dg) demonstrates sample loading into the FEP tube. <br>
1. Cut 9 cm of FEP tube. <br>
2. Insert the FEP tube inside the 'FEP tube adapter'. Attach 1 cm of the silicone rubber tube to the end of the FEP tube. <br>
3. Cover dechorionated embryos with 0.8 % low melting imaging grade agarose with 0.5x Tricaine mesylate on a 3 cm cell culture dish. <br>
4. Attach a borosilicate glass Pasteur pipette to the pipette pump and aspirate one or more zebrafish embryos into the pipette. <br>
5. Insert the tip of the pipette into the silicone rubber tube and gently transfer the embryo to the center of the FEP tube. Allow the agarose in the FEP tube to solidify. <br><br>
<span><img src="support/media/iCAT-41.jpg" width="250"></span>
<span><img src="support/media/iCAT-40.jpg" width="250"></span> 
<div style="page-break-before: always;">

6. Gently insert the FEP tube into the 'chamber'. Using a syringe, apply grease inside the openings at the top of the 'chamber'. The grease will fill the gaps and seal the FEP tube in place. 
<br><br>
<span><img src="support/media/iCAT-39.jpg" width="500"></span> 

7. Tight the 'FEP tube adapter' screw to fix it to the axial motor. Clean the grease from the surface of the FEP tube using a soft, lint-free tissue. Rotate the tube as needed to ensure thorough cleaning. Fill the 'chamber' with water. Launch iCAT and set up the desired 'chamber' temperature using the [GUI](#processing). <br>

*NOTE: Frequent on-and-off cycling of the Peltier element can cause expansion and contraction of the 'chamber', leading to inconsistent imaging during long time-lapse experiments. To address this, we developed an algorithm that gradually reaches the set-point temperature and then applies a constant power to the Peltier element to maintain it. Once the target temperature is reached, this power level remains stable throughout the experiment, preventing thermal fluctuations that could otherwise cause 'chamber' expansion or shrinkage. The algorithm performs reliably with default parameters when used in conjunction with the specified Peltier element and under standard ambient conditions (20–25 °C). If needed, these parameters can be fine-tuned in the* [```main.pde```](https://github.com/osvobo/iCAT/tree/main/main.pde) *Processing sketch is possible:*<br>
```
float multiplier = 1 + ((targetT - 28)/(1/0.20));
int hp0 = Math.round(6 * multiplier);
int hp1 = Math.round(30);
float deltaT0 = 0;
float deltaT1 = 4;
int hp = Math.round( (hp0 * (deltaT1 - deltaT) - hp1 * (deltaT0 - deltaT)) / (deltaT1 - deltaT0) );
```
*Where:<br>
``hp0`` and ``hp1`` are the heating power levels 0 and 1 <br>
``deltaT0`` and ``deltaT1`` are the temperature thresholds at which ``hp0`` or ``hp1`` are activated, defined as the difference between the setpoint and the actual temperature. <br> 
``multiplier`` increases ``hp0`` by 0.20 for each degree Celsius above 28°C. <br>
``hp`` is linearly increasing heating power applied when the actual temperature falls within the range defined by deltaT0 and deltaT1.<br><br>
Alternatively, to avoid modifying the code, users can simply adjust the heating output using the built-in **'adjustment knob'**: turning it counterclockwise reduces power, while turning it clockwise increases it.<br>
<br>*

8. Use intuitive axial rotation wheel to orient your sample along its x-axis.
<br><div style="page-break-before: always;">

### Part 6: Special functions
This section provides a detailed explanation of the functions of individual [GUI](#processing) buttons and other features of the software. 
<br>

**Reset camera position:** <br>
Use the **Camera slider control** to center the camera preview. If the slider reaches its limits, use the **reset button** to recenter it based on the current view.
<br><br>

**Camera control:** <br>
Use the **Camera resolution buttons** to adjust the resolution. To take a single snapshot, press the **s button**. To activate or deactivate continuous mode, press the **c button**. By default, the camera screen displays the middle portion of the captured image. To scroll up or down, use the Camera vertical crop slider **Camera vertical crop slider**.
<br><br>

**Logging and data storage:** <br>
The iCAT generates following log files within its root folder: <br>
```
iCAT\logs\log\log_YYYY-MM-DD_HH-mm-ss.txt
iCAT\logs\rotate\rotate_YYYY-MM-DD_HH-mm-ss.txt
```
The ```log_*.txt``` file stores all serial communication between the Arduino and the PC to which Processing is connected, while the ```rotate_*.txt``` log specifically records the rotary movements. <br>
The images captured by the camera are stored here: <br>
```
iCAT\logs\log\capture_no_YYYY-MM-DD_HH-mm-ss.txt
```
<br>

**Remote axial control:** <br>
The iCAT controlling software enables remote axial rotation control, which can be achieved in two ways: <br>

1. **File-based control:** The iCAT Processing software continuously monitors the ```iCAT\logs\temp\``` folder for the presence of a ```temp.txt file```. If such a file is found and contains an integer value, the control software adds this value to the current axial position and uses the result as the target angle for axial rotation. The ```temp.txt``` file is subsequently renamed to prevent repeated use.

2. **Trigger-based control:** Remote rotation can also be activated using trigger input (IN) signals. This requires the trigger IN cable to be connected to the [Trigger IN port](#iCAT-20a) and a valid signal to be sent. The signal is a 5 ms, 5 V pulse typically generated by the microscope trigger board via the microscope control software. After sending this signal, a 2-second delay should be introduced in the microscope software before imaging begins to allow sufficient time for the iCAT's FEP tube rotation and to minimize potential vibrations.
<br>
To activate the triggering, the **Interval button** must be active, and rotation angles must be configured within the **Rotation step-size control**. The **upper slider** determines the rotation amount.
<br>
If two different rotation angles are needed for independent, consecutive trigger inputs, the second desired angle can be set using the **bottom slider**. This feature is particularly useful for alternating the specimen's rotation back and forth. To achieve this, configure a value in the **upper slider** and set its negative equivalent in the **bottom slider**.
<br><br>

**Step-size control:** <br>
Additionally, the rotation step-size can also be controlled manually. As with the trigger inputs, set the desired angle(s) using the slider(s). To apply the angle change, press the corresponding **push button**.
<br><br>

**Home point:** <br>
By default, iCAT always recovers the last known axial angle position based on the stored value within this log:
```
iCAT\logs\rotate\rotate_YYYY-MM-DD_HH-mm-ss.txt
```
It is also possible to save the **HOME position** by adjusting the axial angle and pressing the **set H button**. Once this button is active, toggling the **go H button** will move to the saved angle position. If the **set H button** is inactive, pressing the **go H button** will move to the default position — 0°.
<br><br>

**iCAT-ZEN (ZEISS) synchronization:**<br>
iCAT can be fully synchronized with the software that controls the microscope. In our showcase example, we developed integration with the **ZEN software**, which is used to control **ZEISS microscopes**. This integration utilizes custom-made [macros](zen) that need to be loaded into the ZEN macro folder: ```Documents\Carl Zeiss\ZEN\Documents\Macros``` and that need to be run in parallel with the iCAT software.<br>
A demonstration of this integration can be seen in this [video](https://youtu.be/mFEu0ixnI0U).<br>
These macros are used in two steps:
1. During the first step, the [iCAT-mapping_setup.czmac](zen/iCAT-mapping_setup.czmac) macro is activated. This guides the user through the calibration of a 3D space. The user is prompted to focus and center the specimen within two distinct angle orientations, thereby generating a 2D model of the specimen's orientation within the FEP tube.
2. Once the mathematical model is created, the user can activate the [iCAT-mapping_sync.czmac](zen/iCAT-mapping_sync.czmac) macro to enable automatic synchronization of the focus and the stage with axial rotation adjustments. This feature is particularly useful when the specimen is mounted eccentrically.
<br><div style="page-break-before: always;">

### Start imaging!
![pic](support/media/iCAT-24.jpg)
<br><br>

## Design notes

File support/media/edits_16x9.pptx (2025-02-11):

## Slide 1

Obsah obrázku kancelářské potřeby, interiér, červená Popis byl vytvořen automaticky

Black jumper caps

M0

M1

M2

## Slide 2

New version, see illustrator

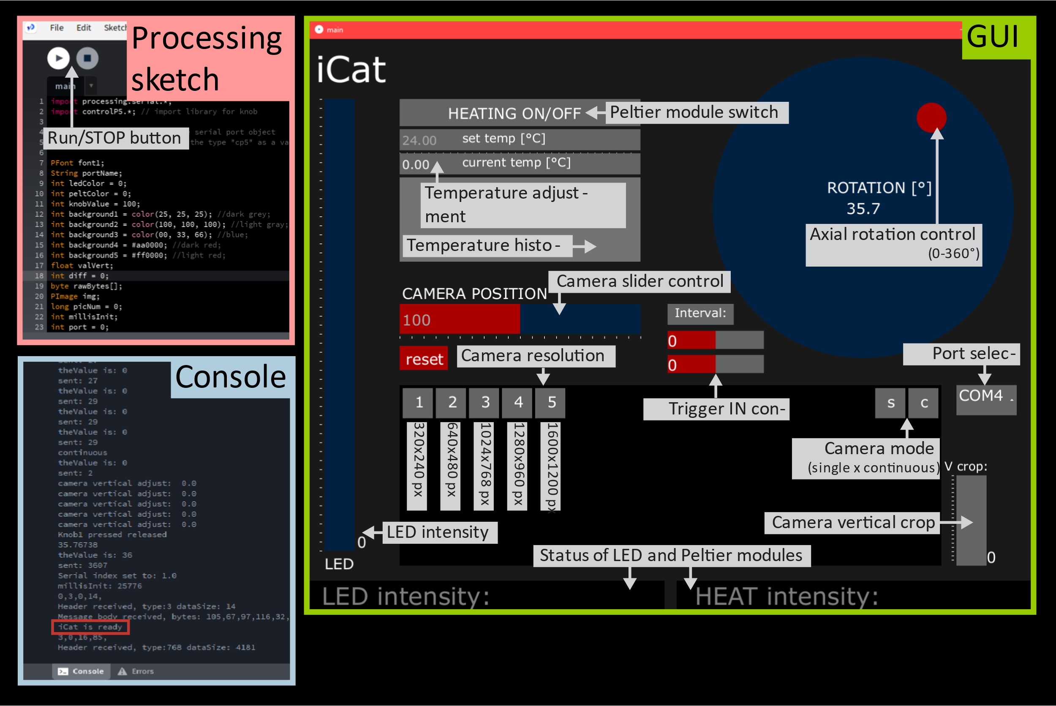
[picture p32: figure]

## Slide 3

Processing sketch

Run iCat

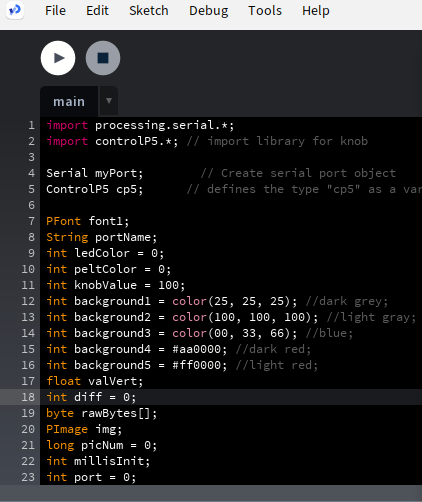
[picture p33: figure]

Old version, for a new one see illustrator

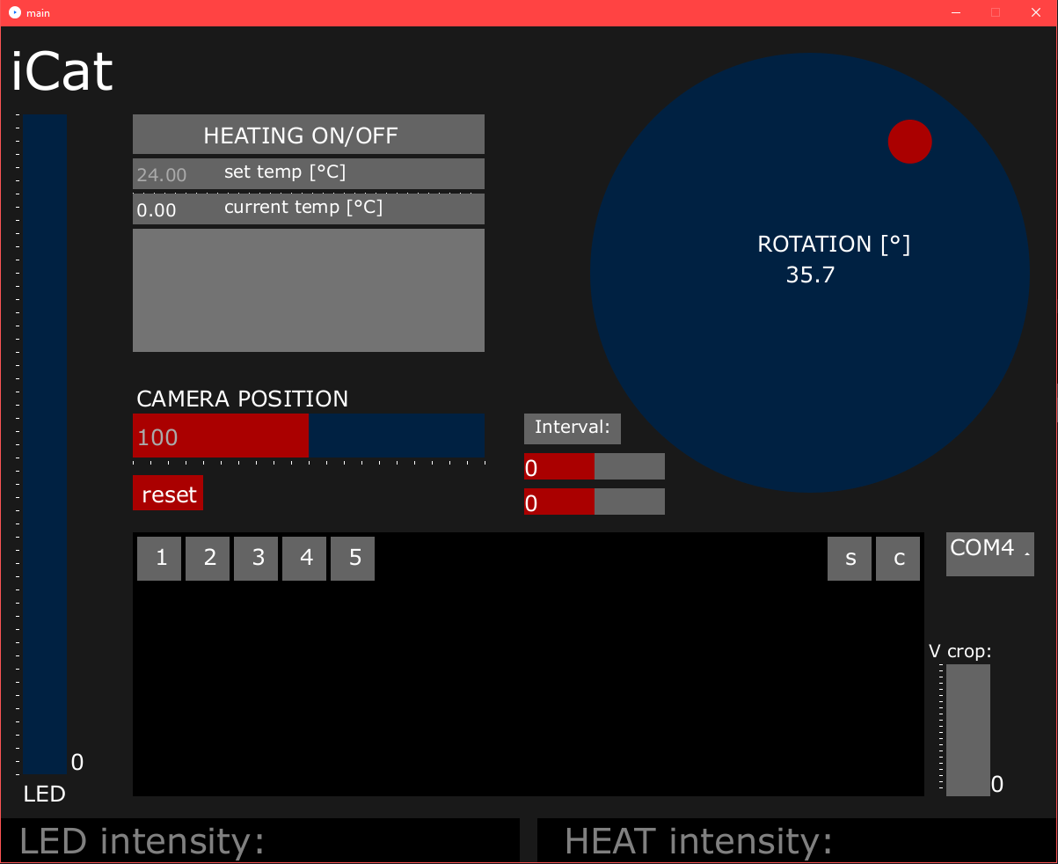
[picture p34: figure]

GUI

Peltier switch

axial control

temperature setting and graph

console

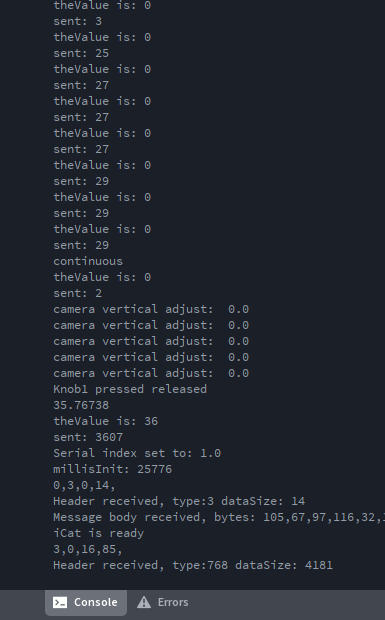
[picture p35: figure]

camera position control

camera resolution

port selection

trigger IN control

single/continuous mode

LED intensity

camera vertical cropping

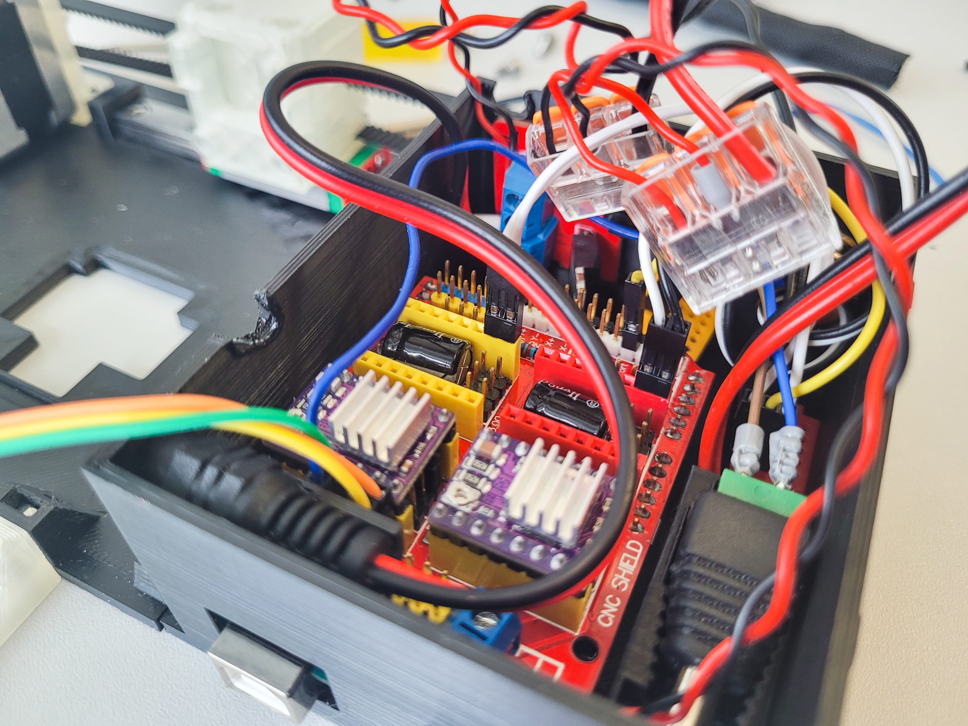
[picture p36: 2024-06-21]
support/media/iCAT-35.jpg

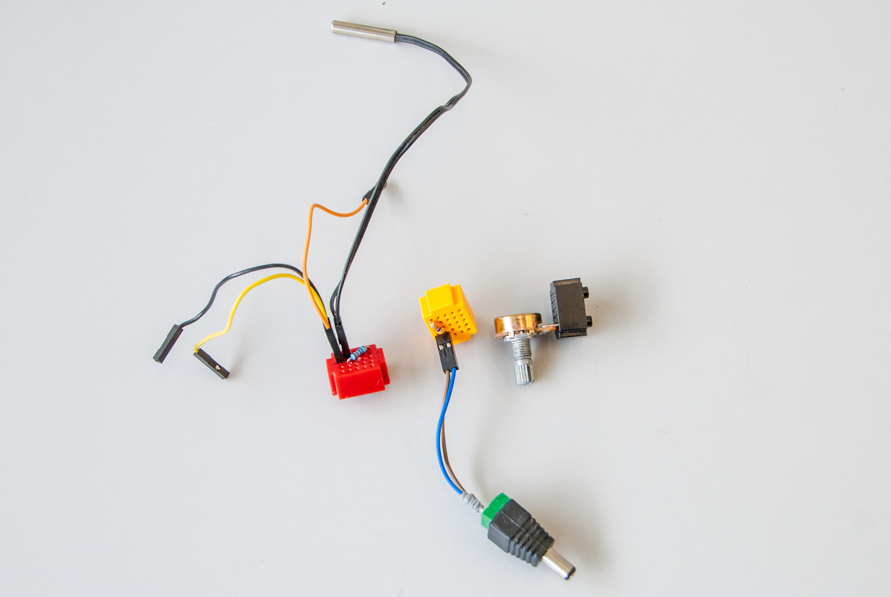
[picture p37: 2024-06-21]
support/media/iCAT-13.jpg

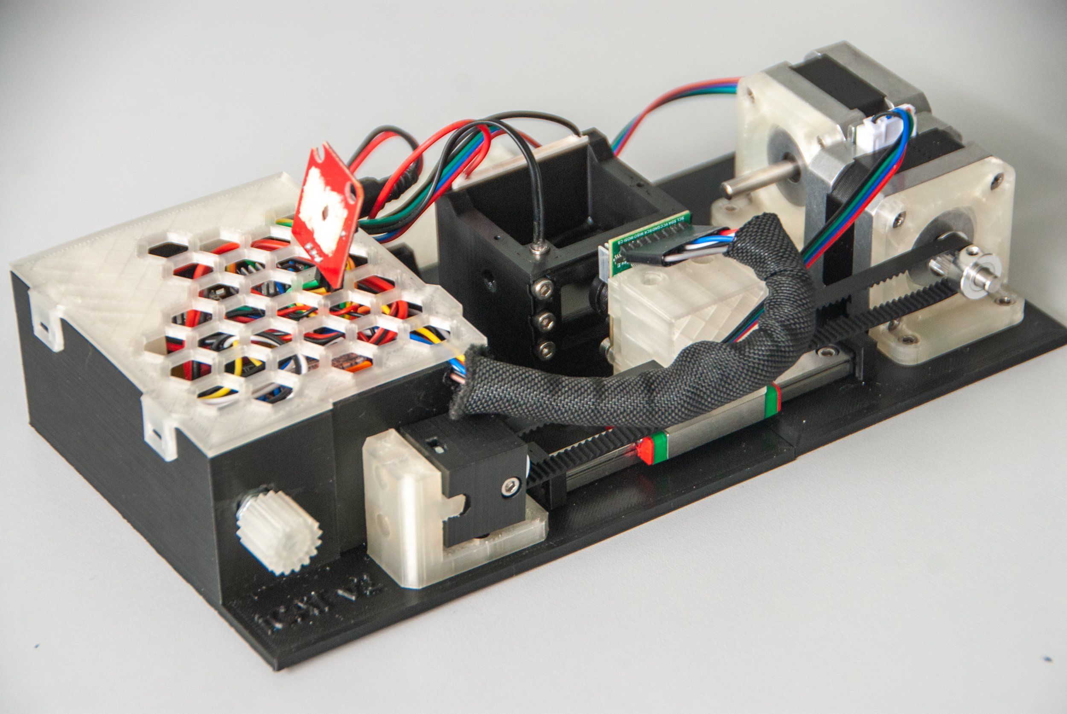
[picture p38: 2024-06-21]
support/media/iCAT-22.jpg

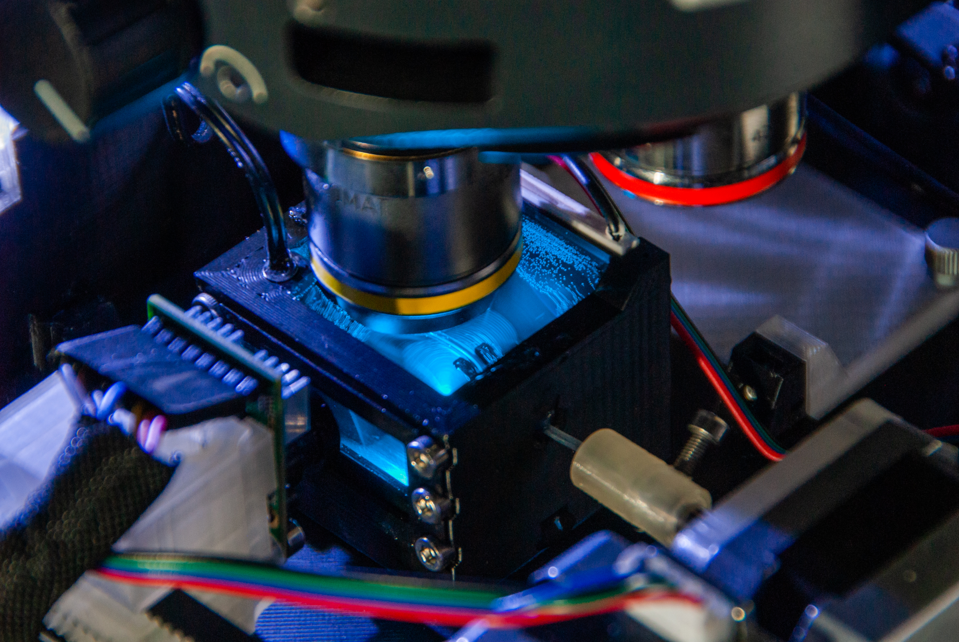
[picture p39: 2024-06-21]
support/media/iCAT-26.jpg

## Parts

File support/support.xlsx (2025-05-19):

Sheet: comparison
 | Axial rotation | Image resolution | Multi positioning | Modularity | Ease of assembly | In-built temperature control | Autonomous mode | Suitability for remote control | Price | Material | Reference
Lightsheet/Open SPIM | yes | + | + | + | + | ? | + | ? | $$$ | Metal | https://www.ncbi.nlm.nih.gov/pubmed/19465594
 |  |  |  |  |  |  |  |  |  |  | https://www.ncbi.nlm.nih.gov/pubmed/23749300
 |  |  |  |  |  |  |  |  |  |  | https://www.ncbi.nlm.nih.gov/pubmed/23749304
VAST (Union Biometrica) | yes | +++ | +++ | + | - | no | + | ++ | $$$ | Metal | https://www.ncbi.nlm.nih.gov/pubmed/20639868
 |  |  |  |  |  |  |  |  |  |  | https://www.ncbi.nlm.nih.gov/pubmed/22159032
 |  |  |  |  |  |  |  |  |  |  | https://www.ncbi.nlm.nih.gov/pubmed/23403568
Other custom-made devices | yes | ++ | - | ++ | ++ | ? | ? | ? | $$ | Metal | https://www.ncbi.nlm.nih.gov/pubmed/25946260
 |  |  |  |  |  |  |  |  |  |  | https://www.ncbi.nlm.nih.gov/pubmed/24023880
 |  |  |  |  |  |  |  |  |  |  | https://www.ncbi.nlm.nih.gov/pubmed/28700724
Magnetic and acoustic based devices | yes | ++ | - | + | + | ? | ? | ? | $$ | Metal | https://pubmed.ncbi.nlm.nih.gov/30487638/
 |  |  |  |  |  |  |  |  |  |  | https://www.ncbi.nlm.nih.gov/pubmed/33602914
iCat | yes | +++ | ++ | +++ | +++ | yes | +++ | +++ | $ | 3D printed | https://github.com/osvobo/iCat/

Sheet: components
 |  |  | Option 1 |  |  | Option 2
 | Item | Quantity | Price | Hyperlink | Note | Price | Hyperlink | Note |  | Option 1 | Option 2
Electronics | Arduino Uno Rev3 | 1 | $27.6 | https://www.amazon.com/Arduino-A000066-ARDUINO-UNO-R3/dp/B008GRTSV6 | - | $26.7 | https://www.aliexpress.us/item/3256805071306083.html | - | Electronics | $175.10 | $128.45
 | Arducam | 1 | $40.0 | https://www.amazon.com/Arducam-Module-Camera-Arduino-Mega2560/dp/B013JUKZ48/ | - | $63.0 | https://www.alibaba.com/product-detail/ARDUCAM-5MP-PLUS-OV5642-MINI-CAM_1600630833583.html | - | Accessories | $222.40 | $62.18
 | IRF520 Driver Module | 1 | $4.5 | https://www.ebay.com/itm/253658203940 | - | $0.5 | https://www.aliexpress.com/item/32967974360.html | - | Wiring | $57.24 | $28.62
 | CNC Shield V3 | 1 | $8.0 | https://www.amazon.com/WWZMDiB-CNC-Shield-V3-Engraving/dp/B0BQDW1H8Z/ | - | $2.4 | https://www.aliexpress.com/item/1005002756457153.html | - | 3D printing (incl. printer) | $627.84 | $696.80
 | DRV8825 Stepper Motor Driver | 2 | $20.0 | https://www.amazon.com/Teyleten-Robot-Printer-DRV8825-StepStick/dp/B0CP92T4QR/ | - | $3.8 | https://www.aliexpress.com/item/1005006133851072.html | - | 3D printing (filament only) | $115.84 | $47.80
 | 17HS2408 Stepper Motor | 2 | $33.9 | https://www.amazon.com/Printer-17HS2408-Stepper-Certification-4-Lead/dp/B098L2R5M4/ | - | $18.3 | https://www.aliexpress.com/item/1005005074685168.html | - | Tools | $69.76 | $30.20
 | Peltier plate module TEC1-12706 | 1 | $9.8 | https://www.amazon.com/HiLetgo-TEC1-12706-Semiconductor-Refrigeration-Thermoelectric/dp/B00M1PM7H6/ | - | $3.2 | https://www.aliexpress.com/item/1005006080475551.html | - | TOTAL (incl. printer) | $1152.34 | $946.25
 | NTC Thermistor 10K 1% 3950 | 1 | $2.4 | https://www.ebay.com/itm/315179700963 | - | $0.4 | https://www.aliexpress.com/item/1005002882657685.html | - | TOTAL (iCat) | $640.34 | $297.25
 | 4.7 kOhm resistor | 1 | $5.5 | https://www.amazon.com/EDGELEC-Resistor-Tolerance-Resistance-Optional/dp/B07HDFLWNB | 100 pcs | $1.5 | https://www.aliexpress.com/item/1005005669886834.html | 100 pcs
 | 10 kOhm resistor | 1 | $5.5 | https://www.amazon.com/EDGELEC-Resistor-Tolerance-Resistance-Optional/dp/B07HDFLWNB | 100 pcs | $1.5 | https://www.aliexpress.com/item/1005005669886834.html | 100 pcs
 | 10K Ohm potentiometer | 1 | $9.3 | https://www.amazon.com/HiLetgo-Single-Joint-Potentiometer-Variable-Resistors/dp/B00MCK7JMS/ | 20 pcs | $1.7 | https://www.aliexpress.com/item/1005006259158854.html | 5 pcs
 | 3W High Power LED Module LED with PCB Chassis for Arduino | 1 | $1.0 | https://www.ebay.com/itm/255345211017 | - | $1.6 | https://www.aliexpress.com/item/1005006127462938.html | -
 | 12V 3A Power Supply | 1 | $7.8 | https://www.amazon.com/Power-Supply12Volt-Adapter-Connectivity-Devices/dp/B0BMPYVBDT/ | - | $3.8 | https://www.aliexpress.com/item/1005005815301733.html | -
Accessories | GT2 Pulley 16 Teeth 5mm bore 6 mm width | 1 | $7.0 | https://www.amazon.com/WINSINN-Aluminum-Synchronous-Timing-Printer/dp/B077GMR328/r | 5 pcs | $1.8 | https://www.aliexpress.com/item/32781681772.html | -
 | GT2 Idler 20 Teeth 5mm bore 3 mm width without teeth | 1 | $7.3 | https://www.amazon.com/HJ-Garden-Aluminium-Synchronous-Mechanical/dp/B07LGTSYQ5/ | 2 pcs | $0.6 | https://www.aliexpress.com/item/32890073873.html | -
 | GT2 Open Timing Belt 2mm Pitch 6mm Width | 1 | $10.0 | https://www.amazon.com/SIMAX3D-Alumium-20teeth-3D-Printer/dp/B07TZZ2YCS/ | 5 meters | $3.7 | https://www.aliexpress.com/item/32921042288.html | -
 | MGN9H 100mm linear guide rail with carriage | 1 | $11.5 | https://www.amazon.com/100mm-Miniature-Bearing-Linear-Motion/dp/B07MR1S43Z/ | - | $5.9 | https://www.aliexpress.com/item/1000007480470.html | -
 | Stainless Steel DIN912 Hexagon Hex Socket Head Cap Allen Bolt Screw, M3x4, M3x5, M3x6, M3x14 | 4 | $35.1 | https://www.amazon.com/Ochoos-Stainless-DIN912-Hexagon-Socket/dp/B07R68NQYP/ | - | $7.2 | https://www.aliexpress.com/item/10000139502321.html | 3x50 pcs
 | M3 hex nut | 1 | $9.0 | https://www.amazon.com/Mriuuod-Hex-M3-Nuts-Replacement/dp/B0CR3S4MZT/ | 100 pcs | $4.5 | https://www.aliexpress.com/item/1005003241995713.html | 10x10 pcs
 | Microscope Cover Glass, 24x40mm | 1 | $10.0 | https://www.amazon.com/Microscope-Cover-Glass-24x40mm-thickness/dp/B00CD80JI0/ | 100 pcs | $3.0 | https://www.alibaba.com/product-detail/Medical-Micro-18x18-20x20-22x22-24x24_1600166160763.html | 10 pcs
 | Lubricant in the syringe | 1 | $20.0 | https://www.amazon.com/Krytox-GPL-205-GD0-Lubricant-GPL-205-Mechanical-Stabilizers/dp/B0CQV2TXLB/ | - | $23.0 | https://www.allworldmachinery.com/itemdetail/?itemCode=NBU-15%20%2830CC%20SYRINGE%29 | -
 | Sleeving Cord Protector, 6-12 mm | 1 | $9.0 | https://www.amazon.com/Alex-Tech-10ft-Protector-Sleeving/dp/B07FW3GTXB/ | 10 ft | $2.9 | https://www.aliexpress.com/item/1005003923351753.html | 1/3 meter
 | Neodymium Magnet 5mm x 2mm | 1 | $7.0 | https://www.amazon.com/Magnets-Refrigerator-Neodymium-Whiteboard-Kitchen/dp/B0CCXY6WBR/ | 50 pcs | $0.9 | https://www.aliexpress.com/item/1005002285099311.html | 50 pcs
 | FEP tube clear 0.8 I.D./1.2 O.D. | 1 | $66.8 | https://www.proliquid.de/index.php?Schlauchfinder | 25 meters | $1.0 | https://www.alibaba.com/product-detail/Small-size-clear-FEP-tube-and_62201607168.html | 10 meters, this source has not been tested
 | FEP tube clear - other sizes | 1 | $22.3 | https://www.bola.de/en/tubing-bola?c=179 | 5 meters | - | -
 | Silicon rubber tube 1x2 mm | 1 | $7.6 | https://www.amazon.com/Quickun-Silicone-Brewing-Kegerator-Aquaponics/dp/B08JQQ68R7/ | 3 meters | $7.6 | https://www.aliexpress.com/item/32999887844.html | -
Wiring | Male Female Plug 12V DC Power Pigtail Cable Jack | 1 | $11.9 | https://www.amazon.com/43x2pcs-Connector-Security-Surveillance-MILAPEAK/dp/B07CWQPPTW/ | 10+10 pcs | $11.7 | https://www.aliexpress.com/item/1005004599068177.html | 5 pcs
 | Female And Male DC Connectors 2.1x5.5mm | 1 | $0.0 | https://www.amazon.com/43x2pcs-Connector-Security-Surveillance-MILAPEAK/dp/B07CWQPPTW/ | 10+10 pcs | $2.3 | https://www.aliexpress.com/item/1005005601514426.html | 5+5 pcs
 | Crimp Terminals Set Kit | 1 | $7.0 | https://www.amazon.com/Electrical-Terminals-Connectors-0-5-2-5mm2-Inflaming/dp/B078S6SMQ2/ | - | $3.6 | https://www.aliexpress.com/item/32977835401.html | -
 | Dupont Line M-M + F-M + F-F Jumper Wire 10cm, 20CM | 2 | $19.0 | https://www.amazon.com/Solderless-Multicolor-Electronic-Breadboard-Protoboard/dp/B09FPJ9TSP/ | - | $6.5 | https://www.aliexpress.com/item/1005006127479576.html | 3 sets/pc
 | WAGO Terminals Series Splicing Connector 221-413 | 1 | $11.4 | https://www.ebay.com/itm/224381797069 | 10 pcs | $2.1 | https://www.aliexpress.com/item/1005005235755503.html | 10 pcs
 | Mini Solderless Prototype Breadboard | 1 | $8.0 | https://www.amazon.com/Gikfun-Solderless-Prototype-Breadboard-Arduino/dp/B0146MGBWI/ | 7 pcs | $2.4 | https://www.aliexpress.com/item/1005006440382823.html | 7 pcs
 | Black Jumper Caps | 1 | $5.5 | https://www.amazon.com/ZYAMY-2-54mm-Standard-Circuit-Connection/dp/B077957RN7/ | 30 pcs | $0.4 | https://www.aliexpress.com/item/1005005414075962.html | 100 pcs
3D print | 3D printer | 1 | $512.0 | https://www.prusa3d.com/en/product/original-prusa-mini-semi-assembled-3d-printer-4/ | - | $649.0 | https://www.amazon.com/PRUSA-ORIGINAL-MINI-Semi-Assembled/dp/B0933LV2JW/ | -
 | 3D Printer Filament 1.75mm - transparent, black | 2 | $115.8 | https://www.prusa3d.com/en/category/pla/ | - | $47.8 | https://www.amazon.com/SUNLU-Filament-Transparent-Dimensional-Accuracy/dp/B07ZNG4L9P/ | -
Tools | Pipette Pump 10ml | 1 | $9.0 | https://www.amazon.com/ONiLAB-Pipette-Scientific-Disposable-Pipettes/dp/B0B1QB53F8/ | - | $0.5 | https://www.aliexpress.com/item/1005005171730265.html | -
 | Borosilicate Glass Pasteur Pipettes | 1 | $36.6 | https://www.amazon.com/Kimble-883350-0009-Borosilicate-Pipettes-Disposable/dp/B015145GM6/ | 250 pcs | $8.2 | https://www.aliexpress.com/item/4000432467039.html | 10 pcs
 | Crimping Tools SN-58B + 4 jaws | 1 | $19.0 | https://www.amazon.com/dp/B0BX44TF3R/ | - | $21.0 | https://www.aliexpress.com/item/1005005940788522.html | -
 | Screwdriver Set | 1 | $5.2 | https://www.amazon.com/Screwdriver-Precision-Electronics-Eyeglasses-tasainu/dp/B0BQFG32DV/ | - | $0.5 | https://www.aliexpress.com/item/1005005449368419.html | -
Prices are only approximate and links mainly serve for quick reference
Multiple pieces are included within 1 item most of the time
Purchasing through local stores or other suppliers (www.mouser.com) is recommended

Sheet: pinout diagram
Arduino Pin Number | Input/Output | Function | CNC Shield Pin | iCat Pin | Pinout diagram of CNC shield:
0 | Digital I/O | RX (Serial Input)
1 | Digital I/O | TX (Serial Output)
2 | Digital I/O |  | STEP X | Driver - STEP X
3 | Digital I/O | PWM | STEP Y | MOSFET - PWM
4 | Digital I/O |  | STEP Z | Driver - STEP Y
5 | Digital I/O | PWM | DIR X | Driver - DIR X
6 | Digital I/O | PWM | DIR Y | LED - PWM
7 | Digital I/O |  | DIR Z | Driver - DIR Y
8 | Digital I/O |  | EN | Driver - EN
9 | Digital I/O | PWM | X Endstop
10 | Digital I/O | PWM | Y Endstop | Arducam - CS
11 | Digital I/O | PWM | Z Endstop | Arducam - MOSI
12 | Digital I/O |  | SpnEn | Arducam - MISO
13 | Digital I/O |  | SpnDir | Arducam - SCK
A0 | Analog Input, Digital I/O |  | Abort | Thermistor - NTC
A1 | Analog Input, Digital I/O |  | Hold | Zeiss - IN
A2 | Analog Input, Digital I/O |  | Resume
A3 | Analog Input, Digital I/O |  | Coolant
A4 | Analog Input, Digital I/O |  | SDA | Arducam - SDA
A5 | Analog Input, Digital I/O |  | SCL | Arducam - SCL
AREF | Analog Input | Analog Reference
GND |  | Ground
RESET |  | Reset
3.3V |  | 3.3V Output
5V |  | 5V Output
VIN |  | Voltage Input

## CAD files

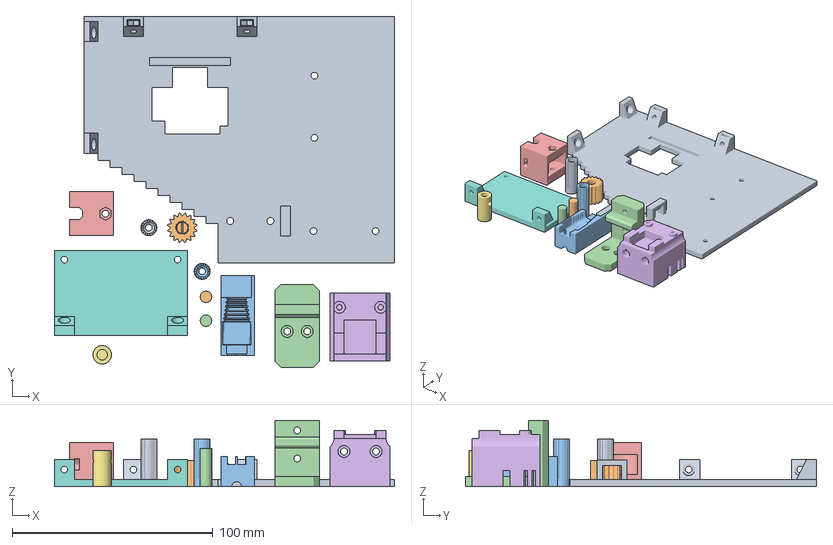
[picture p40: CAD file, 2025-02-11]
support/3D/iCAT-1.3mf
169.7 x 175.0 x 33.0 mm
base-2
knob
base adapter
cargo plate-1
cargo plate-2
cargo
FEP adapter
mounting plate
mounting screw-1 x 2
mounting screw-2 x 2

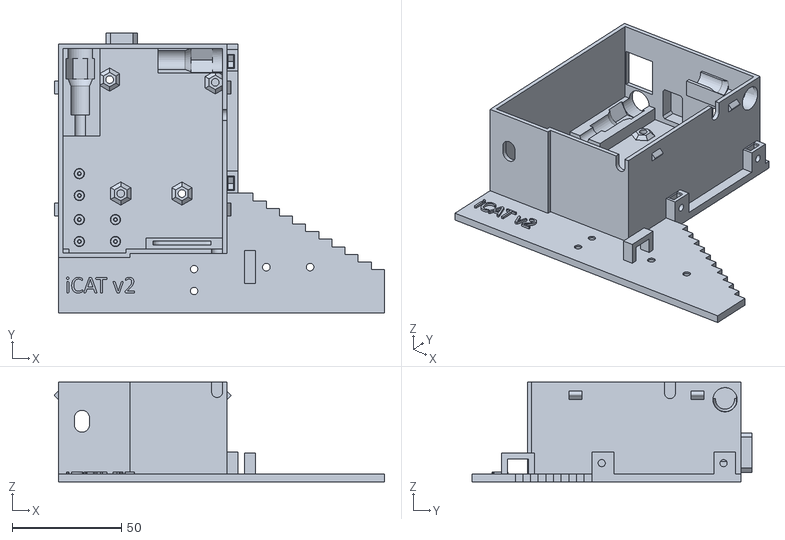
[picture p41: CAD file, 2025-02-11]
support/3D/base-1.stl
150.8 x 128.0 x 45.5

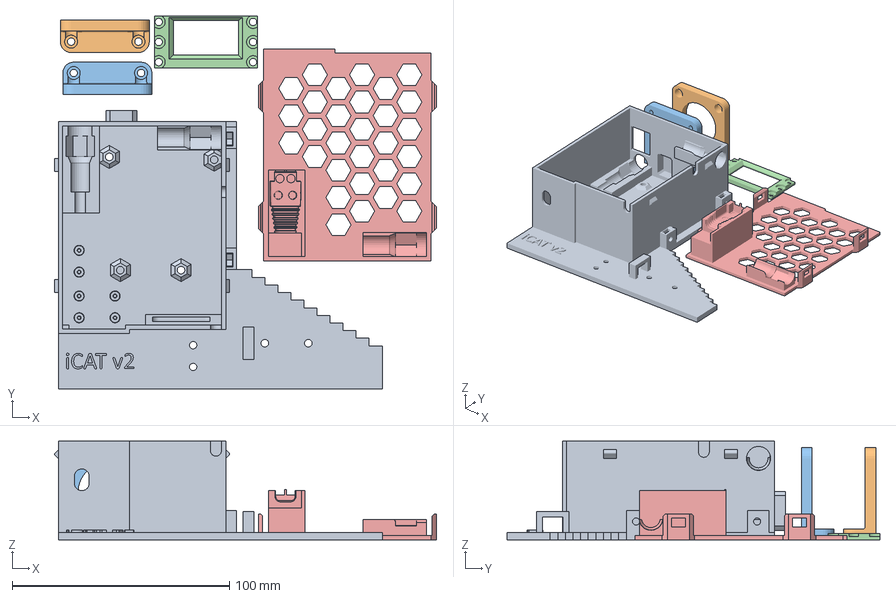
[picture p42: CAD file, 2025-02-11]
support/3D/iCAT-2.3mf
175.8 x 171.5 x 45.5 mm
base-1.stl
motor plate-1
motor plate-2
chamber cover
lid

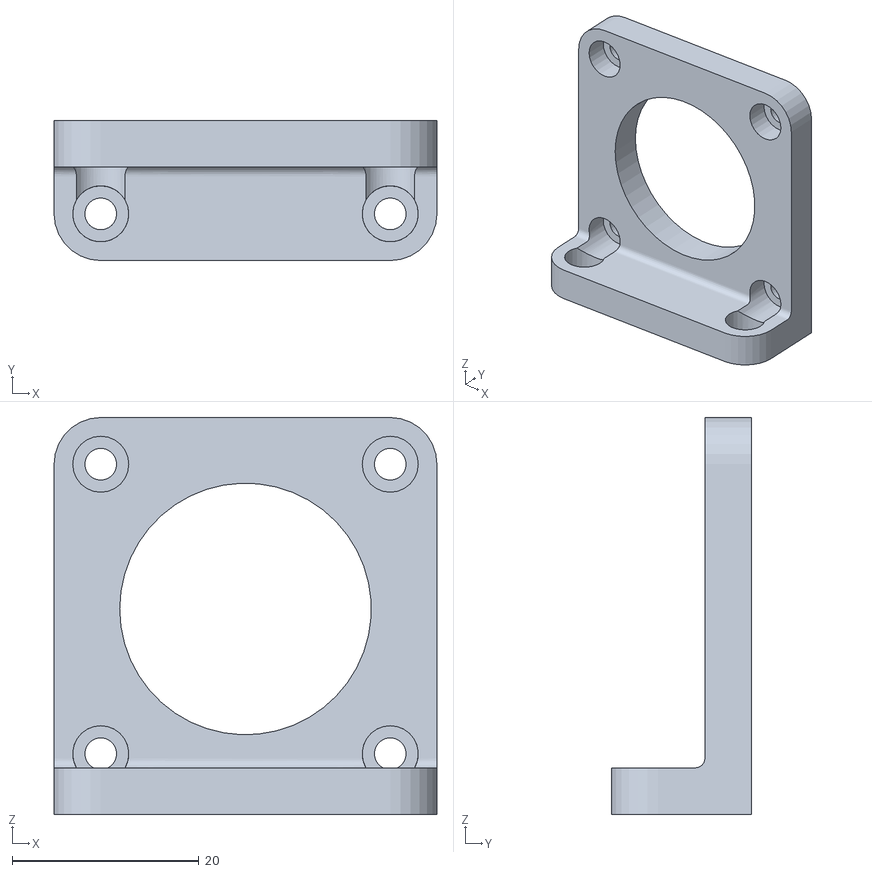
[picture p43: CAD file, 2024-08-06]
support/3D/motor plate-1.stl
41.0 x 15.0 x 42.5

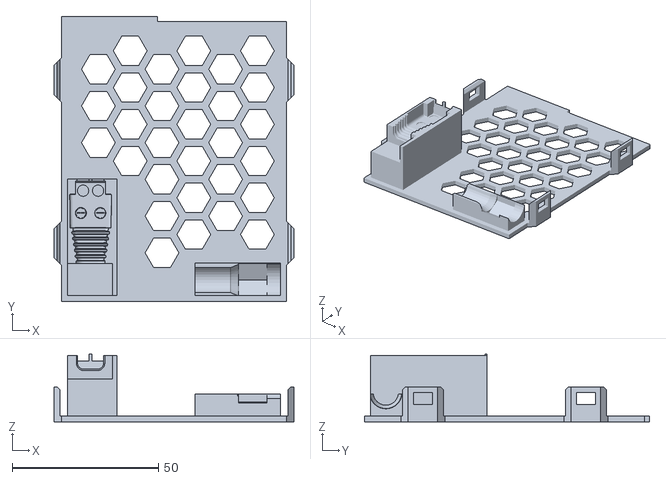
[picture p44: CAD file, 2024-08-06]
support/3D/lid.stl
82.0 x 97.5 x 23.1

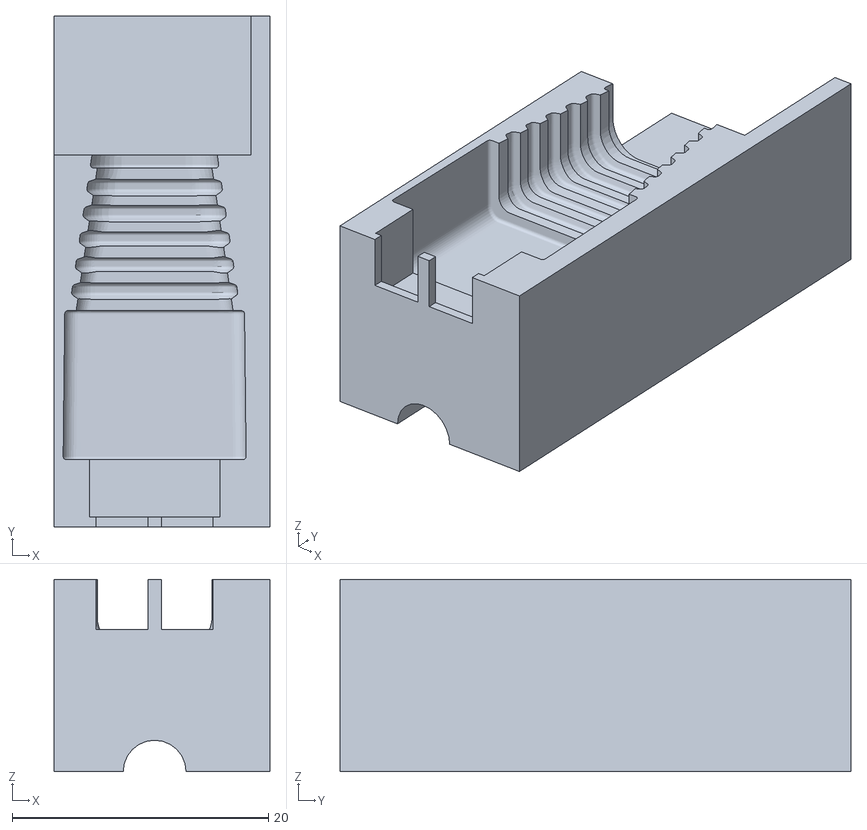
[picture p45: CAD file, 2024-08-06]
support/3D/base adapter.stl
16.8 x 39.9 x 15.0

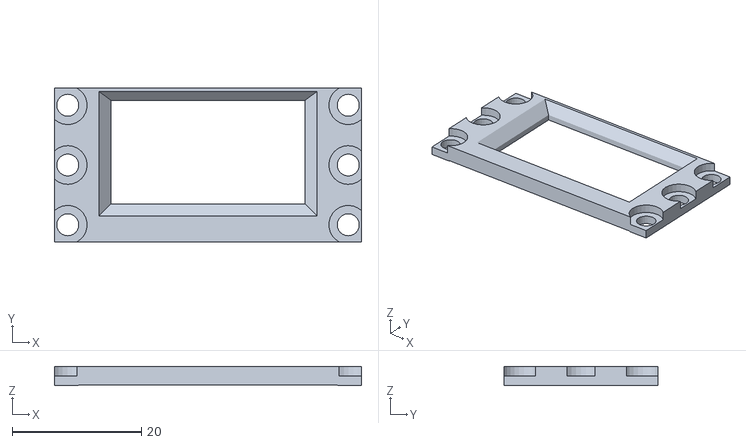
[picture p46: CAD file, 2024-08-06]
support/3D/chamber cover.stl
47.5 x 23.8 x 3.00

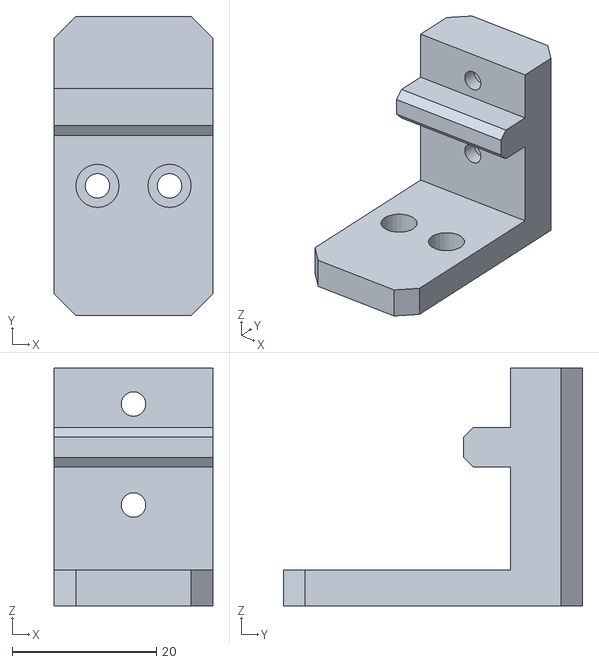
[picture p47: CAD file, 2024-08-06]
support/3D/cargo plate-1.stl
22.0 x 41.5 x 33.0

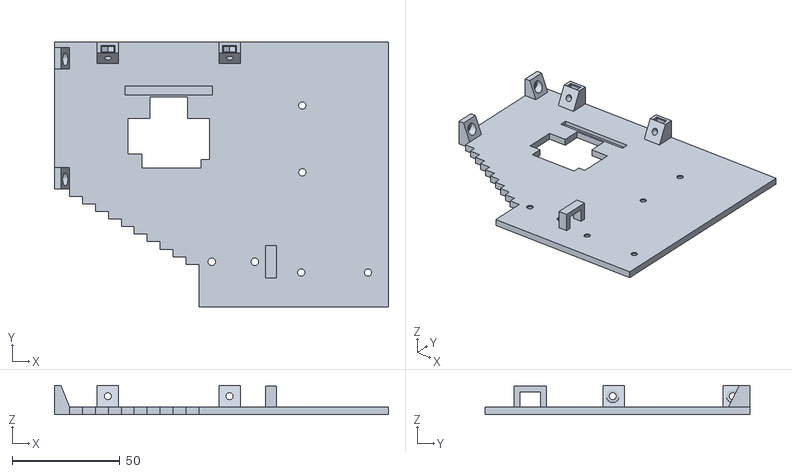
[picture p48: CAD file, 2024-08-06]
support/3D/base-2.stl
155.0 x 123.0 x 13.5

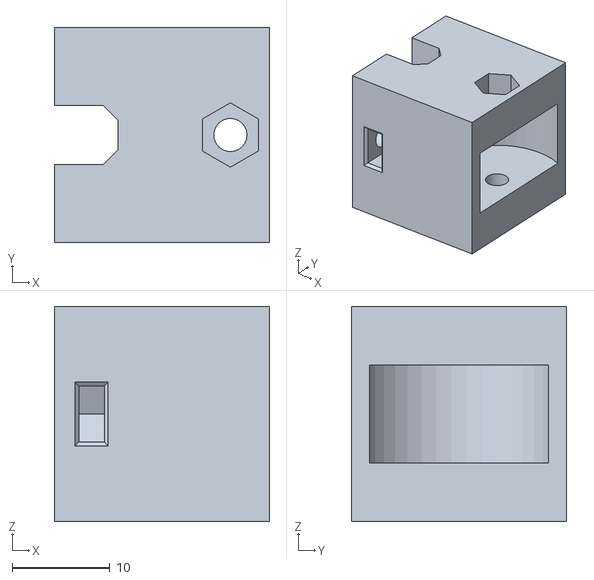
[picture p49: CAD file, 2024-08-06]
support/3D/cargo plate-2.stl
22.0 x 22.0 x 22.0

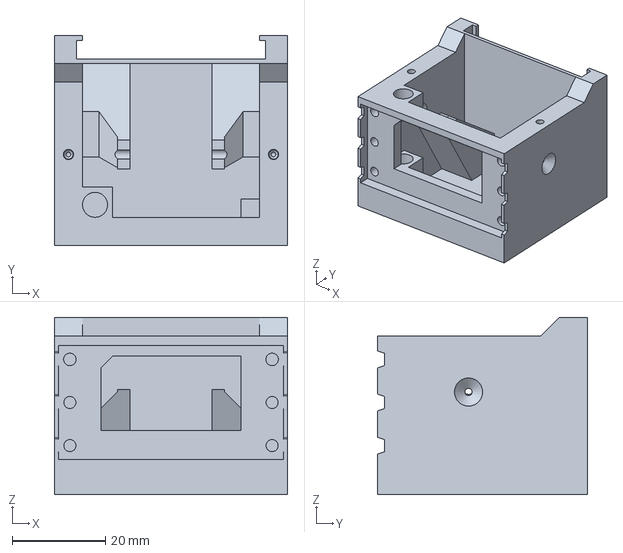
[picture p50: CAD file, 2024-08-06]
support/3D/iCAT-chamber.3mf
50.0 x 45.0 x 38.0 mm

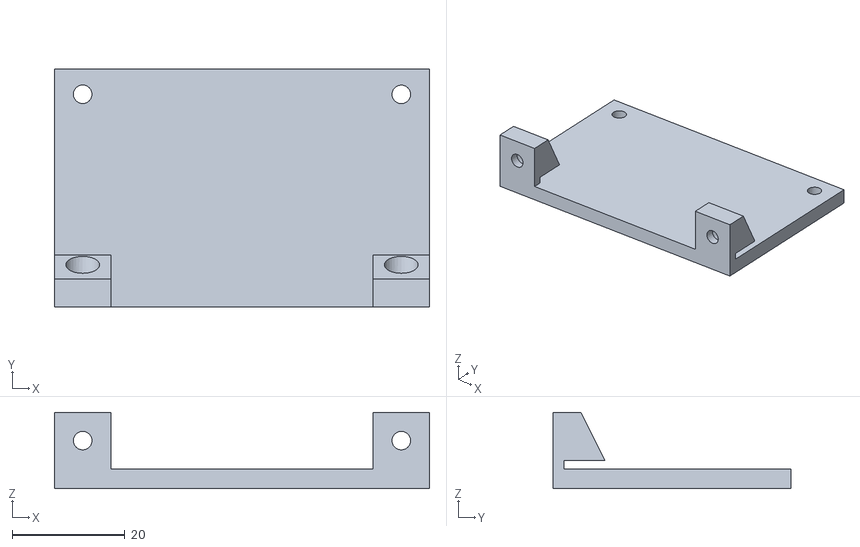
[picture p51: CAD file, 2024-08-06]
support/3D/mounting plate.stl
66.5 x 42.2 x 13.5

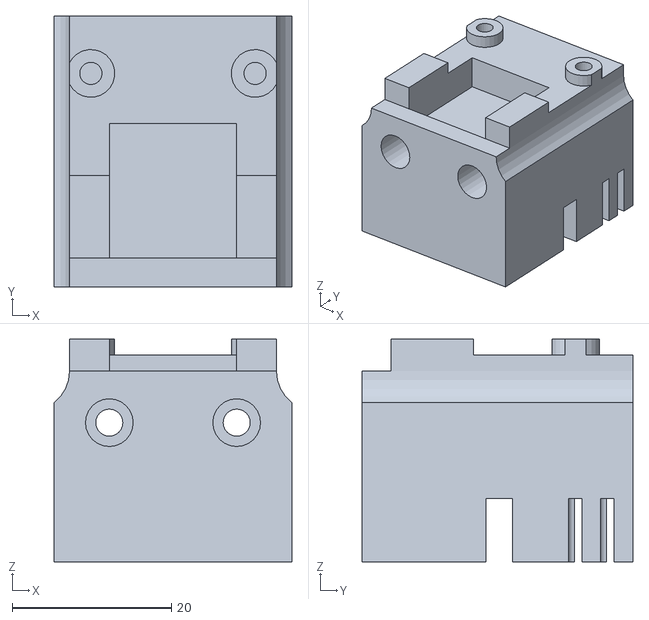
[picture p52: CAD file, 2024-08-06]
support/3D/cargo.stl
29.9 x 34.0 x 28.0

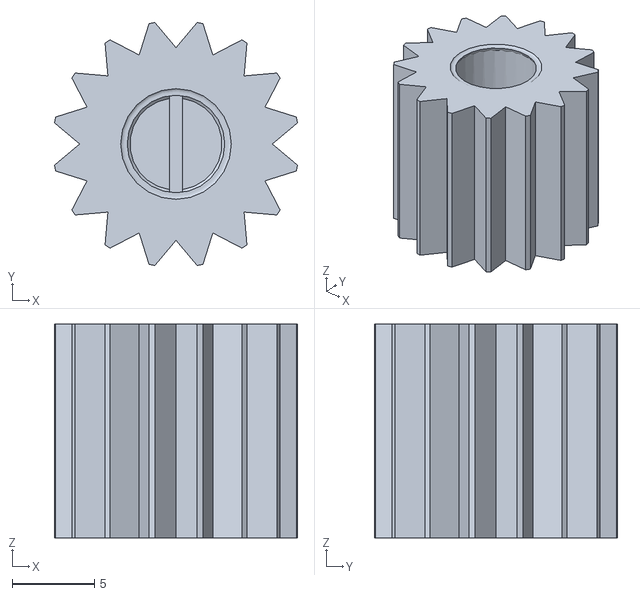
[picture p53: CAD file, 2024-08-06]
support/3D/knob.stl
14.8 x 14.8 x 13.0

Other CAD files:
support/3D/motor plate-2.stl
support/3D/chamber.stl
support/3D/FEP tube adapter.stl
support/3D/mounting screw-2.stl
support/3D/mounting screw-1.stl

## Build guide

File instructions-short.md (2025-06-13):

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

### 3D print:
3D printer, 1x <br>
3D Printer Filament 1.75mm - transparent, black, 2x <br>

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

*NOTE: The complete shopping list is in the [components sheet](https://github.com/osvobo/iCAT/tree/main/support/support.xlsx).* <div style="page-break-before: always;">

## Instructions
### Part 1: 3D printing
All 3D-printed parts can be made using PETG or PLA filaments. For the 'chamber', it is recommended to use a transparent material for the first three layers to allow the use of transmitted light from a microscope. The 'chamber' can be printed in approximately 4 hours, requiring 10.5 meters of filament. For the remaining parts, black filament is recommended to minimize light reflections. Printing these parts takes about 25 hours and consumes 75 meters of filament. The individual STL and 3MF files and the complete Fusion360 project are in the [3D folder](https://github.com/osvobo/iCAT/tree/main/support/3D). The complete iCAT model can also be loaded from the [mesh folder](https://github.com/osvobo/iCAT/tree/main/support/mesh). The STL data can be visualized using 3D slicer software, while the OBJ file can be opened with any mesh viewer, such as the 3D Viewer application in Windows. <br>

### Part 2: iCAT assembly
To assemble iCAT from individual parts, follow the instructions below. If needed, see the [pinout sheet](https://github.com/osvobo/iCAT/tree/main/support/support.xlsx), and the wiring diagram. 
<br><br>
<!-- ![pic](support/fritzing/iCAT_v2.png) -->
<span></span>

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

14. Install the 'Thermistor' breadboard in the 'base'. Connect 'Dupont wires' of all the 'breadboards' as described in step 10. Connect 'LED' to 5 V, ground, and digital output ('Dir Y' pin) on the 'CNC Shield'. Plug eight 'Dupont wires' to the 'Arducam' and connect them to the 'CNC Shield' according to the [pinout sheet](https://github.com/osvobo/iCAT/tree/main/support/support.xlsx) and the wiring diagram. Test the functionality of the device at this point before attaching the 'lid'. 
<br><br>
<span></span><div style="page-break-before: always;">
<span></span>

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

### Part 4: Installation
1. Download the entire repository, or simply download the [Arduino sketch folder](https://github.com/osvobo/iCAT/tree/main/main/), the [```main.pde```](https://github.com/osvobo/iCAT/tree/main/main.pde) Processing sketch, and install the [Processing application](https://processing.org/download). <br>

*NOTE: If you run the [```iCAT.exe```](https://github.com/osvobo/iCAT/tree/main/processing/iCAT.exe) file directly, you will need to install OpenJDK17, as the [Processing sketch folder](https://github.com/osvobo/iCAT/tree/main/processing/) does not contain Java.*<br>

2. Install the [Arduino IDE](https://www.arduino.cc/en/software). <br>
3. Open the Arduino IDE by opening the [```main.ino```](https://github.com/osvobo/iCAT/tree/main/main/main.ino) file. Next, go to the Library Manager and install the [AccelStepper](https://www.airspayce.com/mikem/arduino/AccelStepper/) and [ArduCAM](https://github.com/dennis-ard/ArduCAM) libraries. Once both libraries are installed, press the 'Verify' button to ensure the installation is successful. <br>
4. Check the path of ```memorysaver.h``` file by hovering the mouse over its name at row 5 in the line ```#include "memorysaver.h"```. Then navigate to its folder and replace it with the [```memorysaver.h```](https://github.com/osvobo/iCAT/tree/main/main/memorysaver.h) file provided, which has the camera definition uncommented: <br>
```#define OV5642_MINI_5MP_PLUS``` <br>
5. Test the iCAT by connecting the Arduino to the PC using USB-B cable, connecting the '12 V main power', the 'trigger IN', and the 'Peltier connector'. Open the [```main.pde```](https://github.com/osvobo/iCAT/tree/main/main.pde) and click on the **Run button** in the upper left corner, this will open the Graphical User Interface (GUI) of the iCAT. 
<br><br>

![pic](support/media/processing.jpg) 
<br>

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

*NOTE: Frequent on-and-off cycling of the Peltier element can cause expansion and contraction of the 'chamber', leading to inconsistent imaging during long time-lapse experiments. To address this, we developed an algorithm that gradually reaches the set-point temperature and then applies a constant power to the Peltier element to maintain it. Once the target temperature is reached, this power level remains stable throughout the experiment, preventing thermal fluctuations that could otherwise cause 'chamber' expansion or shrinkage. The algorithm performs reliably with default parameters when used in conjunction with the specified Peltier element and under standard ambient conditions (20–25 °C). If needed, these parameters can be fine-tuned in the* [```main.pde```](https://github.com/osvobo/iCAT/tree/main/main.pde) *Processing sketch is possible:*<br>
```
float multiplier = 1 + ((targetT - 28)/(1/0.20));
int hp0 = Math.round(6 * multiplier);
int hp1 = Math.round(30);
float deltaT0 = 0;
float deltaT1 = 4;
int hp = Math.round( (hp0 * (deltaT1 - deltaT) - hp1 * (deltaT0 - deltaT)) / (deltaT1 - deltaT0) );
```
*Where:<br>
``hp0`` and ``hp1`` are the heating power levels 0 and 1 <br>
``deltaT0`` and ``deltaT1`` are the temperature thresholds at which ``hp0`` or ``hp1`` are activated, defined as the difference between the setpoint and the actual temperature. <br> 
``multiplier`` increases ``hp0`` by 0.20 for each degree Celsius above 28°C. <br>
``hp`` is linearly increasing heating power applied when the actual temperature falls within the range defined by deltaT0 and deltaT1.<br><br>
Alternatively, to avoid modifying the code, users can simply adjust the heating output using the built-in **'adjustment knob'**: turning it counterclockwise reduces power, while turning it clockwise increases it.<br>
<br>*

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

**Logging and data storage:** <br>
The iCAT generates following log files within its root folder: <br>
```
iCAT\logs\log\log_YYYY-MM-DD_HH-mm-ss.txt
iCAT\logs\rotate\rotate_YYYY-MM-DD_HH-mm-ss.txt
```
The ```log_*.txt``` file stores all serial communication between the Arduino and the PC to which Processing is connected, while the ```rotate_*.txt``` log specifically records the rotary movements. <br>
The images captured by the camera are stored here: <br>
```
iCAT\logs\log\capture_no_YYYY-MM-DD_HH-mm-ss.txt
```
<br>

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

1. **File-based control:** The iCAT Processing software continuously monitors the ```iCAT\logs\temp\``` folder for the presence of a ```temp.txt file```. If such a file is found and contains an integer value, the control software adds this value to the current axial position and uses the result as the target angle for axial rotation. The ```temp.txt``` file is subsequently renamed to prevent repeated use.

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

**Home point:** <br>
By default, iCAT always recovers the last known axial angle position based on the stored value within this log:
```
iCAT\logs\rotate\rotate_YYYY-MM-DD_HH-mm-ss.txt
```
It is also possible to save the **HOME position** by adjusting the axial angle and pressing the **set H button**. Once this button is active, toggling the **go H button** will move to the saved angle position. If the **set H button** is inactive, pressing the **go H button** will move to the default position — 0°.
<br><br>

**iCAT-ZEN (ZEISS) synchronization:**<br>
iCAT can be fully synchronized with the software that controls the microscope. In our showcase example, we developed integration with the **ZEN software**, which is used to control **ZEISS microscopes**. This integration utilizes custom-made [macros](https://github.com/osvobo/iCAT/tree/main/zen) that need to be loaded into the ZEN macro folder: ```Documents\Carl Zeiss\ZEN\Documents\Macros``` and that need to be run in parallel with the iCAT software.<br>
A demonstration of this integration can be seen in this [video](https://youtu.be/mFEu0ixnI0U).<br>
These macros are used in two steps:
1. During the first step, the [iCAT-mapping_setup.czmac](https://github.com/osvobo/iCAT/tree/main/zen/iCAT-mapping_setup.czmac) macro is activated. This guides the user through the calibration of a 3D space. The user is prompted to focus and center the specimen within two distinct angle orientations, thereby generating a 2D model of the specimen's orientation within the FEP tube.
2. Once the mathematical model is created, the user can activate the [iCAT-mapping_sync.czmac](https://github.com/osvobo/iCAT/tree/main/zen/iCAT-mapping_sync.czmac) macro to enable automatic synchronization of the focus and the stage with axial rotation adjustments. This feature is particularly useful when the specimen is mounted eccentrically.
<br><div style="page-break-before: always;">

### Start imaging!
![pic](support/media/iCAT-24.jpg)
<br><br>

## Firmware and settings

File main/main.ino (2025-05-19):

#include <AccelStepper.h>  //by Mike McCauley
#include <Wire.h>
#include <ArduCAM.h>
#include <SPI.h>
#include "memorysaver.h"

#define ntc_pin A0
#define ntc_ref 10000
#define temp_ref 25
#define ntc_no 10
#define ntc_beta 3950
#define ntc_resistor 10000
#define dir1 5
#define step1 2
#define dir2 7
#define step2 4
#define EN 8
#define IN A1
#define motorInterfaceType 1

#if !(defined(OV5642_MINI_5MP_PLUS))
#error Please select the hardware platform and camera module in the memorysaver.h, only OV5642 mini 5mp+ will work.
#endif
#define FRAMES_NUM 0x00


// led, temperature, peltier, motors
int pacemaker = 4000;
int led_pin = 6;
int pelt_pin = 3;
int samples[ntc_no];
int interval = 0;
int intervalPin = 0;
int intV = 0;
int int1 = 0;
int int2 = 0;
int inti = 0;
int motor1_temp = 0;
unsigned long t;
float temperature;

// Steepers
long input = 0;
AccelStepper stepper1 = AccelStepper(motorInterfaceType, step1, dir1);
AccelStepper stepper2 = AccelStepper(motorInterfaceType, step2, dir2);

// Arducam
const int CS1 = 10;  // SPI slave for ArduCam
bool CAM1_EXIST = false;
bool continuous = false;
long int streamStartTime;
ArduCAM myCAM1(OV5642, CS1);


void setup() {
  uint8_t vid, pid;
  uint8_t temp;
  Wire.begin();
  Serial.begin(115200);
  //Serial.begin(230400);
  // Serial.begin(150000);

  SendMessage("UNO is connected");

  pinMode(CS1, OUTPUT);
  SPI.begin();
  stepper1.setMaxSpeed(10000);
  stepper1.setAcceleration(500);
  stepper2.setMaxSpeed(10000);
  stepper2.setAcceleration(500);
  pinMode(EN, OUTPUT);
  digitalWrite(EN, HIGH);
  pinMode(IN, INPUT);
  digitalWrite(IN, LOW);

  //initialise camera - check SPI
  while (1) {
    myCAM1.write_reg(ARDUCHIP_TEST1, 0x55);
    temp = myCAM1.read_reg(ARDUCHIP_TEST1);
    if (temp != 0x55) {
      SendMessage("SPI1 interface Error!");
    } else {
      CAM1_EXIST = true;
      SendMessage("SPI1 interface OK.");
    }

    if (!(CAM1_EXIST)) {
      delay(1000);
      continue;
    } else
      break;
  }

  //initialise camera - check OV5642
  while (1) {
    myCAM1.rdSensorReg16_8(OV5642_CHIPID_HIGH, &vid);
    myCAM1.rdSensorReg16_8(OV5642_CHIPID_LOW, &pid);
    if ((vid != 0x56) || (pid != 0x42)) {
      SendMessage("Can't find OV5642 module");
      delay(1000);
      continue;
    } else {
      SendMessage("OV5642 detected");
      break;
    }
  }

  //initialise camera
  myCAM1.set_format(JPEG);
  myCAM1.InitCAM();
  myCAM1.write_reg(ARDUCHIP_TIM, VSYNC_LEVEL_MASK);
  myCAM1.clear_fifo_flag();
  myCAM1.write_reg(ARDUCHIP_FRAMES, FRAMES_NUM);
  myCAM1.OV5642_set_JPEG_size(OV5642_320x240);
  delay(1000);
  myCAM1.clear_fifo_flag();
  SendMessage("iCAT is ready!");
  t = millis();
}

void loop() {
  char logMessage[64];
  serialEvent();

  if (millis() == t + pacemaker) {
    snprintf(logMessage, sizeof(logMessage), "Time: %lu", millis()/1000);
    SendMessage(logMessage);
    ntc(1023);                 //1023 for 5V, 675 for 3.3V
    t = millis();
    if (temperature > 42) {
      pelt(0);
    SendMessage("peltier safety shutdown!!!!");
      }
  }

  if (millis() > t + pacemaker) {
    SendMessage("pacemaker error");
    t = millis();
  }


  intervalPin = analogRead(IN);
  if (intervalPin > 900 && interval == 1) {
    if (int2 == 0) {
      snprintf(logMessage, sizeof(logMessage), "A2: %d", intervalPin);
      SendMessage(logMessage);
      snprintf(logMessage, sizeof(logMessage), "Position before int1: %d", intV);
      SendMessage(logMessage);
      intV = intV + int1;
      snprintf(logMessage, sizeof(logMessage), "Position after int1: %d", intV);
      SendMessage(logMessage);
      motor1(intV);
      delay(1000);
    } else {
      int int12[2];
      int12[0] = int1;
      int12[1] = int2;
      snprintf(logMessage, sizeof(logMessage), "A2: %d", intervalPin);
      SendMessage(logMessage);
      snprintf(logMessage, sizeof(logMessage), "i: %d", inti);
      SendMessage(logMessage);
      snprintf(logMessage, sizeof(logMessage), "int: %d", int12[inti]);
      SendMessage(logMessage);

      snprintf(logMessage, sizeof(logMessage), "Position before int: %d", intV);
      SendMessage(logMessage);
      intV = intV + int12[inti];
      snprintf(logMessage, sizeof(logMessage), "Position after int: %d", intV);
      SendMessage(logMessage);
      motor1(intV);
      motor1(intV);
      delay(1000);
      inti++;
      if (inti == 2) {
        inti = 0;
      }
    }
  }
 // else if (interval == 1) {
 //     snprintf(logMessage, sizeof(logMessage), "A2low: %d", intervalPin);
 //     SendMessage(logMessage);
 // }


  if (CAM1_EXIST && continuous) {
    streamStartTime = millis();
    myCAMSendToSerial(myCAM1);
    long int elapsed = millis() - streamStartTime;
    snprintf(logMessage, sizeof(logMessage), "Camera continuous processing and sending time: %lu", elapsed); //%d
    SendMessage(logMessage);
  }
}

void writeToSerialHeader(uint8_t messageType, uint16_t dataSize) {
  // Write messageType
  byte messageTypeBytes[2] = {0x00, messageType};
  Serial.write(messageTypeBytes, sizeof(messageTypeBytes));

  // Write data size
  byte dataSizeBytes[2];
  dataSizeBytes[0] = (dataSize & 0xFF00) >> 8;
  dataSizeBytes[1] = (dataSize & 0x00FF);

  Serial.write(dataSizeBytes, sizeof(dataSizeBytes));
}

void writeToSerial(uint8_t messageType, uint16_t dataSize, const char data[]) {
  writeToSerialHeader(messageType, dataSize);

  // Write string itself
  Serial.write(data, dataSize);
}

#define MSG_TYPE_TEMPERATURE 1
#define MSG_TYPE_IMAGE 2
#define MSG_TYPE_MESSAGE 3



void SendMessage(const char c[]) {
  writeToSerial(
    MSG_TYPE_MESSAGE,
    strlen(c),
    c
  );
}

void SendTemperature(float temp) {
  uint16_t tempCentiCelsius = (uint16_t) (temp * 100);
  writeToSerial(
    MSG_TYPE_TEMPERATURE,
    2,
    (const char *) &tempCentiCelsius
  );
}

void ntc(int scale) {
  uint8_t i;
  float average;
  for (i = 0; i < ntc_no; i++) {
    samples[i] = analogRead(ntc_pin);
    //delay(10);
  }
  average = 0;
  for (i = 0; i < ntc_no; i++) {
    average += samples[i];
  }
  average /= ntc_no;
  ////Serial.print("Average analog reading "); //Serial.println(average);
  average = scale / average - 1;     // (1023/ADC - 1) USE THIS FOR 5V supply
  average = ntc_resistor / average;  // 10K / (1023/ADC - 1)
  ////Serial.print("Thermistor resistance "); //Serial.println(average);
  temperature = average / ntc_ref;           // (R/Ro)
  temperature = log(temperature);                   // ln(R/Ro)
  temperature /= ntc_beta;                   // 1/B * ln(R/Ro)
  temperature += 1.0 / (temp_ref + 273.15);  // + (1/To)
  temperature = 1.0 / temperature;                  // Invert
  temperature -= 273.15;                     // convert absolute temp to C

  SendTemperature(temperature);
}


void led(int led_val) {
  char logMessage[64];
  snprintf(logMessage, sizeof(logMessage), "Arduino: led %d", led_val);
  SendMessage(logMessage);
  analogWrite(led_pin, led_val);
}

void pelt(int pelt_val) {
  char logMessage[64];
  snprintf(logMessage, sizeof(logMessage), "Arduino: pelt %d", pelt_val);
  SendMessage(logMessage);
  analogWrite(pelt_pin, pelt_val);
}


void motor1(long motor1_val) {
  char logMessage[64];
  snprintf(logMessage, sizeof(logMessage), "Arduino: motor1 %d", motor1_val);
  SendMessage(logMessage);

  motor1_val = motor1_val * 16 / 1.8;  //value * 16(microsteepeing when all 3 pins connected) *200 (steps/cycle) / 360 (°)
  digitalWrite(EN, LOW);
  stepper1.moveTo(motor1_val);
  stepper1.runToPosition();
  digitalWrite(EN, HIGH);
}


void motor2(long motor2_val) {
  char logMessage[64];
  snprintf(logMessage, sizeof(logMessage), "Arduino: motor2 %d", motor2_val);
  SendMessage(logMessage);

  motor2_val = motor2_val * 8;
  digitalWrite(EN, LOW);
  stepper2.moveTo(motor2_val);
  stepper2.runToPosition();
  //Serial.print("motor2 moved to: ");
  //Serial.println(motor2_val);
  digitalWrite(EN, HIGH);
}


void myCAMSendToSerial(ArduCAM myCAM) {
  char logMessage[64];
  char str[8];
  byte buf[5];

  static int i = 0;
  static int k = 0;
  uint8_t temp = 0, temp_last = 0;
  uint32_t length = 0;
  bool jpeg_finished = false;

  myCAM.flush_fifo();       //Flush the FIFO
  myCAM.clear_fifo_flag();  //Clear the capture done flag
  myCAM.start_capture();    //Start capture

  while (!myCAM.get_bit(ARDUCHIP_TRIG, CAP_DONE_MASK));

  length = myCAM.read_fifo_length();

  snprintf(logMessage, sizeof(logMessage), "Sending image, fifoLength: %lu", length);
  SendMessage(logMessage);

  if (length >= 0xffff)  //8M
  {
    SendMessage("Camera capture - over size");
    return;
  }
  if (length == 0)  //0 kb
  {
    SendMessage("Camera capture - size is 0");
    return;
  }

  // Send header through serial line
  writeToSerialHeader(MSG_TYPE_IMAGE, length);

  myCAM.CS_LOW();
  myCAM.set_fifo_burst();

  while (length > 0)
  {
    temp_last = temp;
    temp = SPI.transfer(0x00);

    Serial.write(&temp, 1);
    length--;

    // Handle scenario where we reached end of JPEG - 0xFF 0xD9
    if ((temp == 0xD9) && (temp_last == 0xFF))  //If find the end ,break while,
    {
      while (length > 0) {
        Serial.write(0);
        length--;
      }
    }

  }

  myCAM.CS_HIGH();
}


void serialEvent() {
  long inputRaw;
  char logMessage[64];
  if (Serial.available()) {
    inputRaw = Serial.read();
    if ((inputRaw >= '0') && (inputRaw <= '9')) {
      input = 10 * input + inputRaw - '0';
      ////Serial.println(input);
    } else if (inputRaw == 'e') {
      //Serial.println(input);
      uint8_t start_capture = 0;
      long val = input / 100;
      int inputID;
      inputID = input % 100;
      input = 0;
      ////Serial.println(val);
      ////Serial.println(inputID);


      if (inputID == 9) {
        led(val);
      }

      //if(inputID == 8) {
      //  ntc(1023); //1023 for 5V, 675 for 3.3V
      //}

      if (inputID == 7) {
        ////Serial.println(motor1_temp);
        ////Serial.println(val);
        int motor1_diff = -val - motor1_temp;
        ////Serial.println(motor1_diff);
        if (motor1_diff > -720) {  // this doesnt allow >720 deg rotation
          motor1(-val);
          intV = -val;
          motor1_temp = -val;
        } else {
          //Serial.println("motor1 error, rotation > 720deg isnt allowed!");
        }
      }
      if (inputID == 6) {
        ////Serial.println(motor1_temp);
        ////Serial.println(val);
        int motor1_diff = val - motor1_temp;
        ////Serial.println(motor1_diff);
        if (motor1_diff < 720) {  // this doesnt allow >720 deg rotation
          motor1(+val);
          intV = val;
          motor1_temp = val;
        } else {
          //Serial.println("motor1 error, rotation > 720deg isnt allowed!");
        }
      }

      if (inputID == 5) {
        motor2(val);
      }
      if (inputID == 4) {
        motor2(-val);
      }

      if (inputID == 3) { // && temperature < 35) {
        pelt(val);
      }

      if (inputID == 25) {
        interval = val;
      }
      if (inputID == 26) {
        int1 = val;
      }
      if (inputID == 27) {
        int1 = -val;
      }
      if (inputID == 28) {
        int2 = val;
      }
      if (inputID == 29) {
        int2 = -val;
      }


      if (inputID == 2) {  //cam continuous
        //Serial.println("cam cont sw pressed"); 
        //Serial.println("continuousValue before: " + String(continuous));
        if (continuous) {
          //Serial.println("continuousValue before sw when true: " + String(continuous));
          continuous = false;
        }
        else {
          //Serial.println("continuousValue before sw when false: " + String(continuous));
          continuous = true;
        }
        //Serial.println("continuousValue after sw: " + String(continuous));
      }
      if (inputID == 1) {  //cam snapshot
        if (CAM1_EXIST) {
          streamStartTime = millis();
          myCAMSendToSerial(myCAM1);
          long int elapsed = millis() - streamStartTime;
          snprintf(logMessage, sizeof(logMessage), "Camera processing and sending time: %lu", elapsed);
          SendMessage(logMessage);
        }
      }

      if (inputID == 11) {
        myCAM1.OV5642_set_JPEG_size(OV5642_320x240);
        //Serial.println(F("OV5642_320x240"));
        delay(1000);
        myCAM1.clear_fifo_flag();
      }
      if (inputID == 12) {
        myCAM1.OV5642_set_JPEG_size(OV5642_640x480);
        //Serial.println(F("OV5642_640x480"));
        delay(1000);
        myCAM1.clear_fifo_flag();
      }
      if (inputID == 13) {
        myCAM1.OV5642_set_JPEG_size(OV5642_1024x768);
        //Serial.println(F("OV5642_1024x768"));
        delay(1000);
        myCAM1.clear_fifo_flag();
      }
      if (inputID == 14) {
        myCAM1.OV5642_set_JPEG_size(OV5642_1280x960);
        //Serial.println(F("OV5642_1280x960"));
        delay(1000);
        myCAM1.clear_fifo_flag();
      }
      if (inputID == 15) {
        myCAM1.OV5642_set_JPEG_size(OV5642_1600x1200);
        //Serial.println(F("OV5642_1600x1200"));
        delay(1000);
        myCAM1.clear_fifo_flag();
      }

      //  myCAM1.OV5642_set_JPEG_size(OV5642_2048x1536);
      //  //Serial.println(F("OV5642_2048x1536")); delay(1000);
      //
      //  myCAM1.OV5642_set_JPEG_size(OV5642_2592x1944);
      //  //Serial.println(F("OV5642_2592x1944")); delay(1000);
    }
  t = millis();
  }
}

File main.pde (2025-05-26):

import processing.serial.*;
import controlP5.*; // import library for knob
import java.io.File;
import java.util.Arrays;
import java.util.Comparator;

Serial myPort;        // Create serial port object 
ControlP5 cp5;      // defines the type "cp5" as a variable "type" defined in ControlP5 fo its objects

PFont font1;
String portName;
int ledColor = 0;
int peltColor = 0;
int knobValue = 100;
int background1 = color(25, 25, 25); //dark grey;
int background2 = color(100, 100, 100); //light gray;
int background3 = color(00, 33, 66); //blue;
int background4 = #aa0000; //dark red;
int background5 = #ff0000; //light red;
float valVert;
int diff = 0;
byte rawBytes[];
PImage img;  
long picNum = 0;
int millisInit;
int port = 0;
int HAlign1 = 25;
int HAlign2 = 110;
int HAlign3 = 540;
int HAlign4 = 1200-125;
int home = 0;
int recentValue;
boolean isReady = false; 


//int baud = 650000;
int baud = 115200;
//int baud = 230400;
//int baud = 500000;


Knob Knob1;  
Slider Slider1, Slider2, Slider3, Slider4, Slider5, Slider6, Slider7;
Bang Bang1, Bang2, Bang3, Bang4, Bang5, Bang6, Bang7, Bang8, Bang9, Bang10;
Textlabel Textlabel1, Textlabel2, Textlabel3;
Chart Chart1;
DropdownList DropList1;
Toggle Toggle1, Toggle2, Toggle3, Toggle4;


//output
int sec = second();  // Values from 0 - 59hheea
int min = minute();  // Values from 0 - 59
int hour = hour();    // Values from 0 - 23
int day = day();  
int month = month();
int year = year(); 
PrintWriter output1, output2;


void setup() {
  clear();
  size(1200,950);  
  smooth();  
  noStroke(); 
  
  cp5 = new ControlP5(this);

// font
  PFont f1 = createFont("Verdana",25); 
  ControlFont font1 = new ControlFont(f1);
  ControlFont font2 = new ControlFont(f1, 20);

// colors
  cp5.setColorForeground(background4);
  cp5.setColorBackground(background3);
  cp5.setColorActive(background5); 
  cp5.setFont(font1);

//writer
output1 = createWriter("logs/log/log_" + String.format("%04d-%02d-%02d_%02d-%02d-%02d", year, month, day, hour, min, sec) + ".txt");
output2 = createWriter("logs/rotate/rotate_" + String.format("%04d-%02d-%02d_%02d-%02d-%02d", year, month, day, hour, min, sec) + ".txt");

// serial
  DropList1 = cp5.addDropdownList("myList-DropList1")
          .setPosition(HAlign4-10, 575)
          .setSize(100, 200)
          .setHeight(210)
          .setItemHeight(35)
          .setBarHeight(40)
          .setFont(font2)
          .setColorBackground(background2)
          .setColorActive(background5)
          ;
  DropList1.getCaptionLabel().set("PORT"); //set PORT before anything is selected
  portName = Serial.list()[port]; //0 as default   
  myPort = new Serial(this, portName, baud);   
  //myPort.bufferUntil('\n');
  Label labelDropList1 = DropList1.getCaptionLabel();
  labelDropList1.align(ControlP5.RIGHT_OUTSIDE, CENTER);
  labelDropList1.getStyle().setPaddingTop(5);
  labelDropList1.getStyle().setPaddingLeft(5);


//led
  Slider1 = cp5.addSlider("led")
               .setRange(0,255)
               .setValue(0)
               .setPosition(HAlign1,100)
               .setSize(50,750)
               .setNumberOfTickMarks(51)
               //.setTriggerEvent(Slider.RELEASED)
               //.setColorValue(0xffaaaaaa)
               //.setColorLabel(0xffffffff)
               ;


//motor2
  Slider2 = cp5.addSlider("motor2")
               .setRange(0,200)
               .setValue(100)
               .setLabel("Camera position")
               .setPosition(HAlign2,440)
               .setSize(400,50)
               .setTriggerEvent(Slider.RELEASED)
               .setNumberOfTickMarks(21)
               //.setFont(new ControlFont(f1, 25))
               .setColorValue(0xffaaaaaa)
               .setColorLabel(0xffffffff)
               ;
  Label labelSlider2 = Slider2.getCaptionLabel();
  labelSlider2.align(ControlP5.RIGHT_OUTSIDE, LEFT);
  labelSlider2.getStyle().setPaddingTop(-35);
  labelSlider2.getStyle().setPaddingLeft(-390);


//motor2 reset
 Bang1 = cp5.addBang("bang1")
             .setPosition(HAlign2,510)
             .setSize(80,40)
             .setLabel("reset")
             .setColorForeground(background2)
             .setColorActive(background5)
             ; 
  Label labelBang1 = Bang1.getCaptionLabel();
  labelBang1.align(ControlP5.RIGHT_OUTSIDE, CENTER);
  labelBang1.getStyle().setPaddingTop(0);
  labelBang1.getStyle().setPaddingLeft(-70);
  labelBang1.toUpperCase(false);


//temp out
  Slider3 = cp5.addSlider("tempOut")
               .setRange(24,37)
               .setValue(0)
               .setLabel("set temp [°C]")
               .setPosition(HAlign2,150)
               .setSize(400,35)
               .setNumberOfTickMarks(53)
               .setFont(font2)
               .setTriggerEvent(Slider.RELEASED)
               .setColorValue(0xffaaaaaa)
               .setColorLabel(0xffffffff)
               .setColorBackground(background2)
               ;
  Label labelSlider3 = Slider3.getCaptionLabel();
  labelSlider3.toUpperCase(false);
  labelSlider3.align(ControlP5.RIGHT_OUTSIDE, CENTER);
  labelSlider3.getStyle().setPaddingLeft(-300);
  
  Slider3.addCallback(new CallbackListener() {          
    public void controlEvent(CallbackEvent theEvent) {
      switch(theEvent.getAction()) {
        case(ControlP5.ACTION_RELEASE): case(ControlP5.ACTION_RELEASE_OUTSIDE): case(ControlP5.ACTION_WHEEL):
          println("Slider3 pressed released");
          cp5.getController("heating").setValue(1);
          write(0, 0, 8); //get current temp
          //thermostat();
        break;    
      }
    }
  }); 


//heating on/off
 Toggle1 = cp5.addToggle("heating")
             .setValue(false)
             .setPosition(HAlign2, 100)
             .setSize(400,45)
             .setLabel("heating ON/OFF")
             .setFont(font1)
             .setColorBackground(background2)
             .setColorValue(0xffaaaaaa)
             .setColorLabel(0xffffffff)
             ; 
  Label labelToggle1 = Toggle1.getCaptionLabel();
  labelToggle1.align(ControlP5.RIGHT_OUTSIDE, CENTER);
  labelToggle1.getStyle().setPaddingTop(0);
  labelToggle1.getStyle().setPaddingLeft(-320);
  //labelToggle1.toUpperCase(false);
     
     
// temp input
  Slider4 = cp5.addSlider("tempIn")
               .setLabel("current temp [°C]")
               .setPosition(HAlign2, 190)
               .setSize(400,35)
               .setFont(font2)
               .setColorBackground(background2)
               ;
  Label labelSlider4 = Slider4.getCaptionLabel();
  labelSlider4.toUpperCase(false);
  labelSlider4.align(ControlP5.RIGHT_OUTSIDE, CENTER);
  labelSlider4.getStyle().setPaddingLeft(-300);
  //Slider4.setMultiplier(300); // change Multiplier of the Numberbox ( default is 1 )
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

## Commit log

2023-10-24 added fritzing
    [scope.fzz]
2023-11-23 modified fritzing
    [iCat_pinout&BOM.xlsx, scope_v2.fzz]
2023-11-23 update main and support
    [iCat_pinout&BOM.xlsx]
2023-11-26 added code from PROTOTYPE
2023-12-12 fritzing update
    [scope_v2.fzz]
2024-03-07 updated motor2 direction
2024-08-06 structure and sheets
    [iCat_pinout&BOM.xlsx, iCat_v1.fzz, iCat_v2.fzz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]
2024-08-06 update links
    [iCat_v1.fzz, iCat_v2.fzz]
2024-08-06 update links and add 3d files
    [FEP adapter.stl, adapter.stl, base-1.stl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]
2024-08-12 Revert "Update README.md"
    This reverts commit 0f0d07304e0f46c7d21714550b1b3980c99a59a0.
    [base adapter.stl, iCat1.3mf]
2024-11-29 iCAT rename
    [FEP adapter.stl, base adapter.stl, base-1.stl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]
2024-12-06 obj test
    [test.stl]
2025-05-19 peltier adjustments
    [support.xlsx]
